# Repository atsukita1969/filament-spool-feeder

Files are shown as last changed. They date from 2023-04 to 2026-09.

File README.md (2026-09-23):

# Filament Spool Feeder for Direct-Drive 3D Printers
# ダイレクト式3Dプリンタ用 フィラメントスプールフィーダー

[日本語](#日本語) | [English](#english)

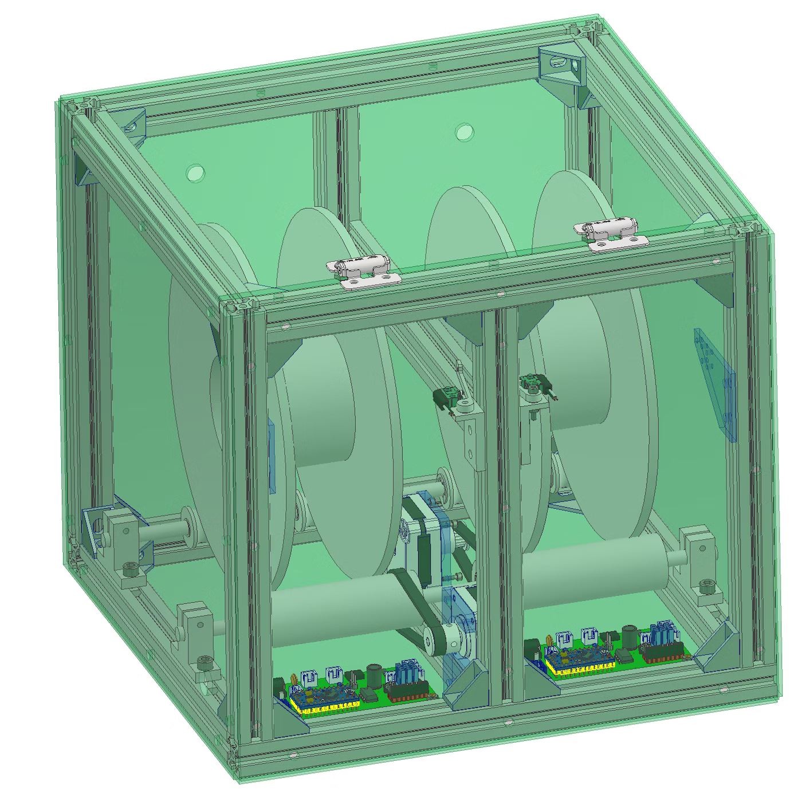
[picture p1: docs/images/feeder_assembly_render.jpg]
Feeder assembly (CAD)


---

## 日本語

### 概要

ダイレクト式（エクストルーダーがヘッドに載っている方式）の3Dプリンタでは、フィラメントをスプールから引き出す力がすべてエクストルーダーにかかります。次のような場面で、フィラメントの引き込みに抵抗がかかり、吐出量が減って品質が落ちます。

- スプールが重い（特に1kg）
- 高速で印刷する
- ノズルがテーブル上でXY方向に大きく移動し、その移動量の分だけフィラメントが引っ張られる

広い部屋ならスプールをプリンタから離して、遊びのフィラメントを長く取れば防げますが、ホビー用途ではその場所がありません。このフィーダーは、ボーデン式とダイレクト式を組み合わせる考え方で、スプールを能動的に回してフィラメントを先に送り出しておく装置です。

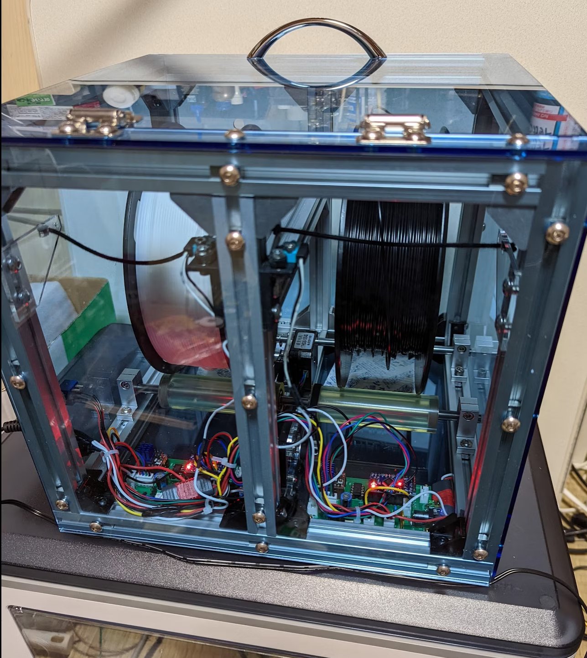
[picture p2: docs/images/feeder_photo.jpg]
Feeder (photo)


### しくみ

1. スプールをウレタンローラーに載せ、ステッピングモーターでGT2ベルトを介してローラーを回します。
2. フィラメントはゴム紐につながったレバーを通ります。一定以上引っ張られるとスイッチが入り、モーターが回ってスプールから送り出します。
3. スイッチが切れた後も一定量（4000ステップ）送り出してから止まります。フィラメントは使用量より多めに送り出され、ゴム紐の伸びとフィラメントのたるみで200mm以上の余裕ができます。
4. 送り要求が異常に長く続いた場合（ジャム）は、独立したマイコン（ATtiny85）がリレーでモーター電源を切り、停止状態を保持します。

詳しくは [docs/principle.md](docs/principle.md) を参照してください。

### リポジトリの構成

| フォルダ | 内容 |
|:--|:--|
| [firmware/](firmware/) | Arduino Pro Mini（メイン制御）と ATtiny85（ジャム監視）のファームウェア |
| [hardware/pcb/](hardware/pcb/) | 制御基板 rev.B（EAGLE データ、回路図 PDF、BOM） |
| [hardware/mechanical/](hardware/mechanical/) | 機構部品（組立外形図、自作部品の STEP データ、BOM） |
| [docs/](docs/) | 原理、配線、画像 |
| [tools/sim/](tools/sim/) | ファームの検証に使った AVR シミュレーション環境 |

### はじめに

1. 機構: [hardware/mechanical/](hardware/mechanical/) の組立外形図、BOM、自作部品の STEP データで組み立てます。
2. 基板: [hardware/pcb/](hardware/pcb/) の EAGLE データで製作します。配線は [docs/wiring.md](docs/wiring.md) にあります。
3. ファーム: [firmware/](firmware/) の手順で、Pro Mini と ATtiny85 に書き込みます。rev.B 基板では、ATtiny85 のファームの `EXT_SENSE_ENABLED` を 1 にします。

### 状態表示LED（改版基板 rev.B）

| LED | 意味 |
|:--|:--|
| 点灯 | 送り要求中 |
| ゆっくり点滅（約1秒周期） | モータードライバが使えない（ジャム監視がモーター電源を切った、など） |
| 速い点滅（約0.25秒周期） | 異常で停止・保持中（リセットで復帰） |
| 消灯 | 待機中 |

### ライセンス

| 対象 | ライセンス |
|:--|:--|
| ハードウェア設計（hardware/） | [CERN-OHL-S-2.0](LICENSES/CERN-OHL-S-2.0.txt) |
| ファームウェアとツール（firmware/, tools/） | [GPL-3.0-or-later](LICENSES/GPL-3.0.txt) |
| 文書と画像（docs/, README など） | [CC BY-SA 4.0](LICENSES/CC-BY-SA-4.0.txt) |

他者のライブラリ、EAGLE ライブラリ要素、購入部品の 3D モデルは対象外です。詳細は [LICENSE.md](LICENSE.md) を参照してください。変更履歴は [CHANGELOG.md](CHANGELOG.md) にあります。2023年に公開した元の状態は、タグ `v1.0-2023` で参照できます。

---

## English

### Overview

On a direct-drive 3D printer (extruder mounted on the print head), the extruder alone has to pull the filament off the spool. The pull resistance reduces the extruded amount and degrades print quality when:

- the spool is heavy (especially 1 kg spools),
- printing fast,
- the nozzle makes long XY travel moves, which pull the filament by the travel distance.

In a large room you can place the spool far from the printer to get a long slack loop, but hobby spaces rarely allow that. This feeder combines the ideas of Bowden and direct drive: it actively turns the spool and pays out filament in advance.

### How it works

1. The spool rests on a urethane roller, driven by a stepper motor through a GT2 belt.
2. The filament passes a lever held by an elastic cord. When the filament is pulled beyond a threshold, a switch closes and the motor turns the spool to pay out filament.
3. After the switch opens, the motor keeps feeding a fixed amount (4000 steps) and stops. More filament is paid out than consumed; the elastic cord and the slack provide more than 200 mm of buffer.
4. If the feed request lasts abnormally long (jam), an independent microcontroller (ATtiny85) cuts the motor supply with a relay and latches the stop.

See [docs/principle.md](docs/principle.md) for details.

### Repository layout

| Folder | Contents |
|:--|:--|
| [firmware/](firmware/) | Firmware for the Arduino Pro Mini (main control) and the ATtiny85 (jam monitor) |
| [hardware/pcb/](hardware/pcb/) | Control board rev.B (EAGLE files, schematic PDF, BOM) |
| [hardware/mechanical/](hardware/mechanical/) | Mechanical parts (outline drawing, STEP files of the self-made parts, BOM) |
| [docs/](docs/) | Principle, wiring, images |
| [tools/sim/](tools/sim/) | AVR simulation used to verify the firmware |

### Getting started

1. Mechanics: build from the outline drawing, the BOM and the STEP files of the self-made parts in [hardware/mechanical/](hardware/mechanical/).
2. Board: make it from the EAGLE files in [hardware/pcb/](hardware/pcb/). Wiring is in [docs/wiring.md](docs/wiring.md).
3. Firmware: flash the Pro Mini and the ATtiny85 as described in [firmware/](firmware/). For board rev.B, set `EXT_SENSE_ENABLED` to 1 in the ATtiny85 firmware.

### Status LED (board rev.B)

| LED | Meaning |
|:--|:--|
| On | Feed requested |
| Slow blink (about 1 s period) | Motor driver not available (e.g. motor supply cut by the jam monitor) |
| Fast blink (about 0.25 s period) | Stopped by a fault and latched (reset to recover) |
| Off | Idle |

### License

| Scope | License |
|:--|:--|
| Hardware design (hardware/) | [CERN-OHL-S-2.0](LICENSES/CERN-OHL-S-2.0.txt) |
| Firmware and tools (firmware/, tools/) | [GPL-3.0-or-later](LICENSES/GPL-3.0.txt) |
| Documentation and images (docs/, README, etc.) | [CC BY-SA 4.0](LICENSES/CC-BY-SA-4.0.txt) |

Third-party libraries, EAGLE library elements and 3D models of purchased parts are not covered. See [LICENSE.md](LICENSE.md). The change history is in [CHANGELOG.md](CHANGELOG.md). The original 2023 state is available as tag `v1.0-2023`.

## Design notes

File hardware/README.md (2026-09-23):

# Hardware / ハードウェア

| Folder / フォルダ | Contents / 内容 |
|:--|:--|
| [pcb/](pcb/) | Control board rev.B: EAGLE files, schematic PDF, BOM / 制御基板 rev.B：EAGLE データ、回路図 PDF、部品表 |
| [mechanical/](mechanical/) | Mechanical parts: outline drawing, STEP files, BOM / 機構部品：組立外形図、STEP データ、部品表 |

Licensed under CERN-OHL-S-2.0, except third-party EAGLE library elements and 3D models of purchased parts. See [LICENSE.md](../LICENSE.md).
CERN-OHL-S-2.0 で公開しています（他者の EAGLE ライブラリ要素と購入部品の 3D モデルを除く）。[LICENSE.md](../LICENSE.md) を参照してください。

Source location: https://github.com/atsukita1969/filament-spool-feeder

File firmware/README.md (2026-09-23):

# Firmware / ファームウェア

[日本語](#日本語) | [English](#english)

| Sketch | MCU | Role |
|:--|:--|:--|
| [feeder_main](feeder_main/) | Arduino Pro Mini (ATmega328P, 5 V, 16 MHz) | Feed control, TMC2130 driver, status LED |
| [jam_monitor_tiny85](jam_monitor_tiny85/) | ATtiny85 | Independent jam monitor, cuts the motor supply with the relay |

Both sketches are compiled by the CI ([.github/workflows/firmware.yml](../.github/workflows/firmware.yml)).

---

## 日本語

### 必要なもの

| 項目 | 内容 |
|:--|:--|
| Arduino IDE | 2.x（または arduino-cli） |
| ボード（メイン） | Arduino AVR Boards の「Arduino Pro or Pro Mini」、Processor「ATmega328P (5V, 16 MHz)」 |
| ボード（ATtiny85） | [ATTinyCore](https://github.com/SpenceKonde/ATTinyCore) 1.5.2 の「ATtiny25/45/85 (No bootloader)」。ボードマネージャ URL: `https://drazzy.com/package_drazzy.com_index.json` |
| ライブラリ | TMCStepper 0.7.3、AccelStepper 1.64（ライブラリマネージャから導入） |
| 書き込み器 | Pro Mini: USB シリアル変換（FTDI 6ピン）。ATtiny85: ISP 書き込み器（Arduino as ISP、USBasp など） |

旧版で使っていた TMC2130Stepper ライブラリは作者により非推奨となったため、後継の TMCStepper に移行しました。TMC2130 に書き込む設定値は旧版と同一です。

### Pro Mini への書き込み（feeder_main）

1. `feeder_main/feeder_main.ino` を開きます（`config.h` も同じフォルダに必要です）。
2. ボード「Arduino Pro or Pro Mini」、Processor「ATmega328P (5V, 16 MHz)」を選びます。
3. USB シリアル変換を Pro Mini の FTDI ヘッダにつなぎ、書き込みます。

### ATtiny85 への書き込み（jam_monitor_tiny85）

ATtiny85 は DIP ソケットに載っているので、基板から外して ISP 書き込み器で書き込みます。

1. ボード「ATtiny25/45/85 (No bootloader)」、Chip「ATtiny85」、Clock「8 MHz (internal)」、B.O.D.「B.O.D. Enabled (2.7v)」を選びます。
2. 書き込み器を選び、「ブートローダを書き込む」を実行します。ブートローダは書き込まれず、クロックと B.O.D. のヒューズだけが設定されます。新品の ATtiny85 は 1 MHz 設定なので、この操作をしないと時間が 8 倍に延びます。
3. 「書き込み装置を使って書き込む」でスケッチを書き込みます。
4. rev.B 基板（X5 を PB4 に接続した基板）では、`EXT_SENSE_ENABLED` を 1 にしてから書き込みます。

### 設定（feeder_main/config.h）

| 項目 | 既定値 | 内容 |
|:--|:--|:--|
| `FEED_STEPS` | 4000 | スイッチ OFF 後の送りステップ数 |
| `MOTION_MODE` | `MOTION_EXPLICIT` | 送りの動かし方。`MOTION_LEGACY` で 2023 年版と同じ呼び出し方になります |
| `EXPLICIT_MAX_SPEED` | 2400 | スイッチ ON 中の最高速度（ステップ/s） |
| `EXPLICIT_ACCEL_UP` | 4000 | ON 中の加速度（ステップ/s²） |
| `EXPLICIT_DECEL` | 2000 | OFF 後の減速度（ステップ/s²） |
| `RUN_CURRENT_MA` / `HOLD_MULT` | 600 / 0.5 | モーター電流（RMS）と保持電流の比 |
| `INPUT_FILTER_MS` | 5 | 送り要求入力のフィルタ時間 |
| `DRIVER_CHECK_MS` | 500 | TMC2130 の状態確認の周期 |
| `BACKUP_TIMEOUT_MS` | 53000 | ソフトウェア側のジャム判定（0 で無効） |

各値の根拠は [docs/principle.md](../docs/principle.md) にあります。

### 設定（jam_monitor_tiny85.ino の先頭）

| 項目 | 既定値 | 内容 |
|:--|:--|:--|
| `JAM_TIMEOUT_MS` | 48000 | 送り要求がこの時間続いたらモーター電源を切る |
| `RELEASE_FILTER_MS` | 20 | これより短い OFF では計時をリセットしない |
| `EXT_SENSE_ENABLED` | 0 | 1 = rev.B 基板の外部入力（PB4）を使う |
| `EXT_FAULT_FILTER_MS` | 50 | 外部入力がこの時間 LOW で異常と判定 |
| `EXT_STARTUP_GRACE_MS` | 1000 | 電源投入後、外部入力が正常になるまで待つ時間 |

### シリアル出力（Pro Mini、115200 bps）

| メッセージ | 意味 |
|:--|:--|
| `feeder_main start` | 起動 |
| `TMC2130: configured and verified` | ドライバ設定完了 |
| `TMC2130: reset / undervoltage detected (motor supply interrupted?)` | モーター電源の瞬断などでドライバがリセットされた（自動で再設定） |
| `TMC2130: not responding` | ドライバが応答しない（モーター電源が切れている、など） |
| `FAULT: TMC2130 overtemperature or short circuit. Latched until reset.` | 過熱・短絡で停止 |
| `FAULT: feed request active too long (jam?). Latched until reset.` | ソフトウェア側のジャム判定で停止 |

### 検証

旧版と新版のバイナリを AVR シミュレーターで動かし、送りの動き、TMC2130 のレジスタ値、保護機能を比較しました。手順と結果は [tools/sim](../tools/sim/) にあります。

---

## English

### Requirements

| Item | Details |
|:--|:--|
| Arduino IDE | 2.x (or arduino-cli) |
| Board (main) | Arduino AVR Boards, "Arduino Pro or Pro Mini", Processor "ATmega328P (5V, 16 MHz)" |
| Board (ATtiny85) | [ATTinyCore](https://github.com/SpenceKonde/ATTinyCore) 1.5.2, "ATtiny25/45/85 (No bootloader)". Boards Manager URL: `https://drazzy.com/package_drazzy.com_index.json` |
| Libraries | TMCStepper 0.7.3, AccelStepper 1.64 (Library Manager) |
| Programmer | Pro Mini: USB-serial adapter (6-pin FTDI). ATtiny85: ISP programmer (Arduino as ISP, USBasp, ...) |

The TMC2130Stepper library used by the old version has been deprecated by its author, so the firmware now uses its successor TMCStepper. The values written to the TMC2130 are identical to the old version.

### Flashing the Pro Mini (feeder_main)

1. Open `feeder_main/feeder_main.ino` (`config.h` must be in the same folder).
2. Select "Arduino Pro or Pro Mini", Processor "ATmega328P (5V, 16 MHz)".
3. Connect a USB-serial adapter to the FTDI header of the Pro Mini and upload.

### Flashing the ATtiny85 (jam_monitor_tiny85)

The ATtiny85 sits in a DIP socket. Take it out and program it with an ISP programmer.

1. Select "ATtiny25/45/85 (No bootloader)", Chip "ATtiny85", Clock "8 MHz (internal)", B.O.D. "B.O.D. Enabled (2.7v)".
2. Select the programmer and run "Burn Bootloader". No bootloader is written; this only sets the clock and B.O.D. fuses. A new ATtiny85 runs at 1 MHz, so without this step all times become 8 times longer.
3. Upload with "Upload Using Programmer".
4. For board rev.B (X5 wired to PB4), set `EXT_SENSE_ENABLED` to 1 before uploading.

### Settings (feeder_main/config.h)

| Item | Default | Meaning |
|:--|:--|:--|
| `FEED_STEPS` | 4000 | Steps fed after the switch opens |
| `MOTION_MODE` | `MOTION_EXPLICIT` | Motion profile. `MOTION_LEGACY` uses the same call pattern as the 2023 firmware |
| `EXPLICIT_MAX_SPEED` | 2400 | Top speed while the switch is on (steps/s) |
| `EXPLICIT_ACCEL_UP` | 4000 | Acceleration while the switch is on (steps/s²) |
| `EXPLICIT_DECEL` | 2000 | Deceleration after the switch opens (steps/s²) |
| `RUN_CURRENT_MA` / `HOLD_MULT` | 600 / 0.5 | Motor current (RMS) and hold current ratio |
| `INPUT_FILTER_MS` | 5 | Filter time of the feed request input |
| `DRIVER_CHECK_MS` | 500 | TMC2130 check period |
| `BACKUP_TIMEOUT_MS` | 53000 | Software jam timeout (0 = off) |

The reasoning behind the values is in [docs/principle.md](../docs/principle.md).

### Settings (top of jam_monitor_tiny85.ino)

| Item | Default | Meaning |
|:--|:--|:--|
| `JAM_TIMEOUT_MS` | 48000 | Cut the motor supply when the feed request lasts this long |
| `RELEASE_FILTER_MS` | 20 | Shorter off periods do not reset the timer |
| `EXT_SENSE_ENABLED` | 0 | 1 = use the external input (PB4) of board rev.B |
| `EXT_FAULT_FILTER_MS` | 50 | External input LOW this long = fault |
| `EXT_STARTUP_GRACE_MS` | 1000 | Time after power-up for the external input to become OK |

### Serial output (Pro Mini, 115200 bps)

| Message | Meaning |
|:--|:--|
| `feeder_main start` | Start-up |
| `TMC2130: configured and verified` | Driver configured |
| `TMC2130: reset / undervoltage detected (motor supply interrupted?)` | Driver was reset, e.g. by a short motor supply interruption (reconfigured automatically) |
| `TMC2130: not responding` | Driver does not respond (e.g. motor supply cut) |
| `FAULT: TMC2130 overtemperature or short circuit. Latched until reset.` | Stopped on overtemperature or short circuit |
| `FAULT: feed request active too long (jam?). Latched until reset.` | Stopped by the software jam timeout |

### Verification

The old and new binaries were run in an AVR simulator to compare motion, TMC2130 register values and protection functions. See [tools/sim](../tools/sim/).

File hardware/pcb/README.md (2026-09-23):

# Control board / 制御基板

[日本語](#日本語) | [English](#english)

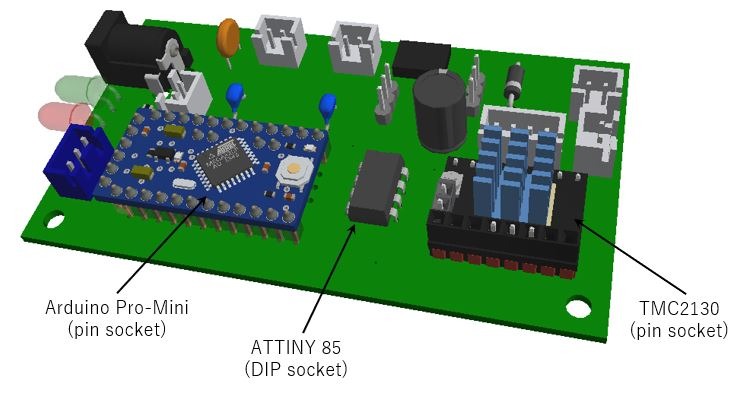
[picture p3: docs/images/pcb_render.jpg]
PCB render (rev.A)


---

## 日本語

### ファイル

| ファイル | 内容 |
|:--|:--|
| [eagle/spool_tmc2130_b.sch](eagle/spool_tmc2130_b.sch) | 回路図 rev.B（Autodesk Fusion から EAGLE 9.7.0 形式で書き出し、XML） |
| [eagle/spool_tmc2130_b.brd](eagle/spool_tmc2130_b.brd) | 基板 rev.B（同上、2層、50 × 90 mm） |
| [spool_tmc2130_b_schematic.pdf](spool_tmc2130_b_schematic.pdf) | 回路図 rev.B の PDF（A3） |
| [bom.csv](bom.csv) | 部品表（rev.A の実装品と rev.B） |

EAGLE データは Autodesk Fusion の Electronics で開けます。KiCad でも取り込めます。配線とピン割り当ては [docs/wiring.md](../../docs/wiring.md) にあります。上の画像は rev.A の基板です。

rev.A（製作済み。発注に使ったデータ）は、タグ [`pcb-rev.A`](https://github.com/atsukita1969/filament-spool-feeder/tree/pcb-rev.A/hardware/pcb) から取り出せます。

### rev.A と rev.B に共通の注意点

- GND は配線ではなく表裏のベタだけで接続しています。
- リレー K1 のコイルは 5V 駆動です。部品は G6K-2P-Y **DC5** を使ってください（DC12 品は 5V では動作しません）。

### rev.B の変更点

| # | 変更 | 理由 |
|:--|:--|:--|
| 1 | X5 の2番と JP2 の1番を EXT_IN から外し、新しいネット EXT_SENSE として ATtiny85 PB4（3番ピン）へ接続。R5（10kΩ）でプルダウン | 外部センサーの異常でモーター電源を切れるようにするため（rev.A では ATtiny85 の出力と衝突して機能しない）。HIGH = 正常、LOW または断線 = 異常。JP2 の1-2 短絡で「外部センサーなし」 |
| 2 | EXT_SENSE と PB4 の間に R6（10kΩ）を直列に追加 | X5 に 5V を超える電圧（最大 12V）が加わっても、ATtiny85 の入力保護ダイオードに流れる電流を約 0.65mA に抑えるため |
| 3 | T1 を DTC144EKA から DTC123JKA に変更（同じ SMT3、同じ端子配置） | 入力電流が 68〜126µA から 1.45〜2.69mA に増え、コイル電流 21.1mA で確実に飽和する |
| 4 | R2 を 680Ω から 2.2kΩ に変更 | 抵抗の損失を約 0.045W に下げる |
| 5 | D3 を D4 ネットから外し、Pro Mini D8 → D3 → R4 → GND で駆動。R4 を 150Ω から 470Ω に変更 | X9 にどの種類のセンサーでも接続できるようにし、LED で状態を表示するため。D8 の電流は約 6mA |
| 6 | チップ抵抗 R1〜R6 を 0603 から 0805（2012）に変更 | 手はんだをしやすくするため |

部品の配置：R5 は X5 の近く、R6 は U2 の近くにあります。R2 と R3 は表面、ほかのチップ部品（R1、R4、R5、R6、T1、U1）は裏面です。

### rev.B の使い方

- ATtiny85 のファームは `EXT_SENSE_ENABLED` を 1 にして書き込みます（[firmware/](../../firmware/)）。
- 外部センサーを使わないときは、JP2 の1-2 を短絡します。
- X5 には、正常なときに2番を HIGH にするセンサーをつなぎます。例：1-2 間の常閉接点（正常で閉じ、異常や断線で開く）、または 5〜12V を出力するセンサー。NPN オープンコレクタ出力は HIGH を出せないので、そのままでは使えません。

### rev.B の確認

- DRC は、GND の小さい SMD パッド5か所（T1 のE、R1・R3・R4・R5 の1番）で「銅箔幅」を報告します。パッドの短辺（1.0〜1.03mm）が GND ネットクラスの最小幅 1.524mm より細いためで、パッドはベタに直接つながっています。ほかのエラーはありません。
- 製造データ（CAM 出力のガーバー）の銅箔を解析し、26 ネットすべてが設計どおりにつながり、ショートや孤立した銅箔がないことを確かめました。

### rev.A（製作済み）の注意点

- T1（DTC144EKA）はデータシート上の駆動能力に余裕がありません。実機では動いていますが、rev.B で変更しました。
- R2（680Ω、0603）は 12V で約 0.15W 消費し、一般的な 0603 抵抗の定格 0.1W を超えます。
- ATtiny85 を実装したまま JP2 を短絡しないでください。
- 以前公開していた DesignSpark 版のデータは、EAGLE からの変換時に GND ベタが GND ネットから外れていたため削除しました。タグ `v1.0-2023` から参照できます。

ファームは rev.A と rev.B の両方に対応しています（[firmware/](../../firmware/)）。

---

## English

### Files

| File | Contents |
|:--|:--|
| [eagle/spool_tmc2130_b.sch](eagle/spool_tmc2130_b.sch) | Schematic rev.B (exported from Autodesk Fusion in EAGLE 9.7.0 format, XML) |
| [eagle/spool_tmc2130_b.brd](eagle/spool_tmc2130_b.brd) | Board rev.B (same format, 2 layers, 50 × 90 mm) |
| [spool_tmc2130_b_schematic.pdf](spool_tmc2130_b_schematic.pdf) | Schematic rev.B as PDF (A3) |
| [bom.csv](bom.csv) | Bill of materials (rev.A as built and rev.B) |

The EAGLE files open in Autodesk Fusion Electronics and can be imported into KiCad. Wiring and pin assignment are in [docs/wiring.md](../../docs/wiring.md). The picture above shows the rev.A board.

rev.A (built; the data used for fabrication) is available in tag [`pcb-rev.A`](https://github.com/atsukita1969/filament-spool-feeder/tree/pcb-rev.A/hardware/pcb).

### Notes for both rev.A and rev.B

- GND is connected only through the top and bottom copper pours, not by traces.
- The coil of relay K1 is driven from 5 V. Use G6K-2P-Y **DC5** (the DC12 version does not operate on 5 V).

### Changes in rev.B

| # | Change | Reason |
|:--|:--|:--|
| 1 | Disconnect X5 pin 2 and JP2 pin 1 from EXT_IN and route them as a new net EXT_SENSE to ATtiny85 PB4 (pin 3), with a 10 kΩ pull-down R5 | Lets an external sensor cut the motor supply (on rev.A it conflicts with the ATtiny85 output and does not work). HIGH = OK, LOW or broken wire = fault. JP2 1-2 fitted = no external sensor |
| 2 | Add R6 (10 kΩ) in series between EXT_SENSE and PB4 | Limits the current into the input protection diode of the ATtiny85 to about 0.65 mA when more than 5 V (up to 12 V) is applied to X5 |
| 3 | T1: DTC144EKA → DTC123JKA (same SMT3 package and pinout) | Input current rises from 68–126 µA to 1.45–2.69 mA, so the transistor saturates reliably at the 21.1 mA coil current |
| 4 | R2: 680 Ω → 2.2 kΩ | Reduces the resistor dissipation to about 0.045 W |
| 5 | Disconnect D3 from the D4 net and drive it from Pro Mini D8 → D3 → R4 → GND; R4: 150 Ω → 470 Ω | Any type of sensor can then be used on X9, and the LED shows the status. D8 current about 6 mA |
| 6 | Chip resistors R1–R6: 0603 → 0805 (2012) | Easier hand soldering |

Placement: R5 is near X5 and R6 is near U2. R2 and R3 are on the top side; the other chip parts (R1, R4, R5, R6, T1, U1) are on the bottom side.

### Using rev.B

- Flash the ATtiny85 with `EXT_SENSE_ENABLED` set to 1 ([firmware/](../../firmware/)).
- Fit JP2 1-2 when no external sensor is used.
- Connect a sensor to X5 that drives pin 2 HIGH when everything is OK, for example a normally closed contact between pins 1 and 2 (closed = OK, open or broken wire = fault), or a sensor with a 5–12 V output. An NPN open-collector output cannot drive HIGH and does not work as is.

### Checks on rev.B

- The DRC reports "copper width" at five small GND SMD pads (T1 E, pin 1 of R1, R3, R4 and R5). The short side of these pads (1.0–1.03 mm) is narrower than the 1.524 mm minimum width of the GND net class; the pads are connected directly to the pour. There are no other errors.
- The copper of the manufacturing data (Gerber files from the CAM processor) was analysed: all 26 nets are connected as designed, with no shorts and no isolated copper.

### Notes on rev.A (built)

- T1 (DTC144EKA) has no guaranteed drive margin according to its datasheet. It works on the built boards but was changed in rev.B.
- R2 (680 Ω, 0603) dissipates about 0.15 W at 12 V, above the 0.1 W rating of a standard 0603 resistor.
- Do not fit JP2 while the ATtiny85 is installed.
- The DesignSpark files published earlier were removed because the GND pour lost its connection to the GND net in the conversion from EAGLE. They are still available in tag `v1.0-2023`.

The firmware supports both rev.A and rev.B ([firmware/](../../firmware/)).

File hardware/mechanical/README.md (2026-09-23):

# Mechanical parts / 機構部品

[日本語](#日本語) | [English](#english)

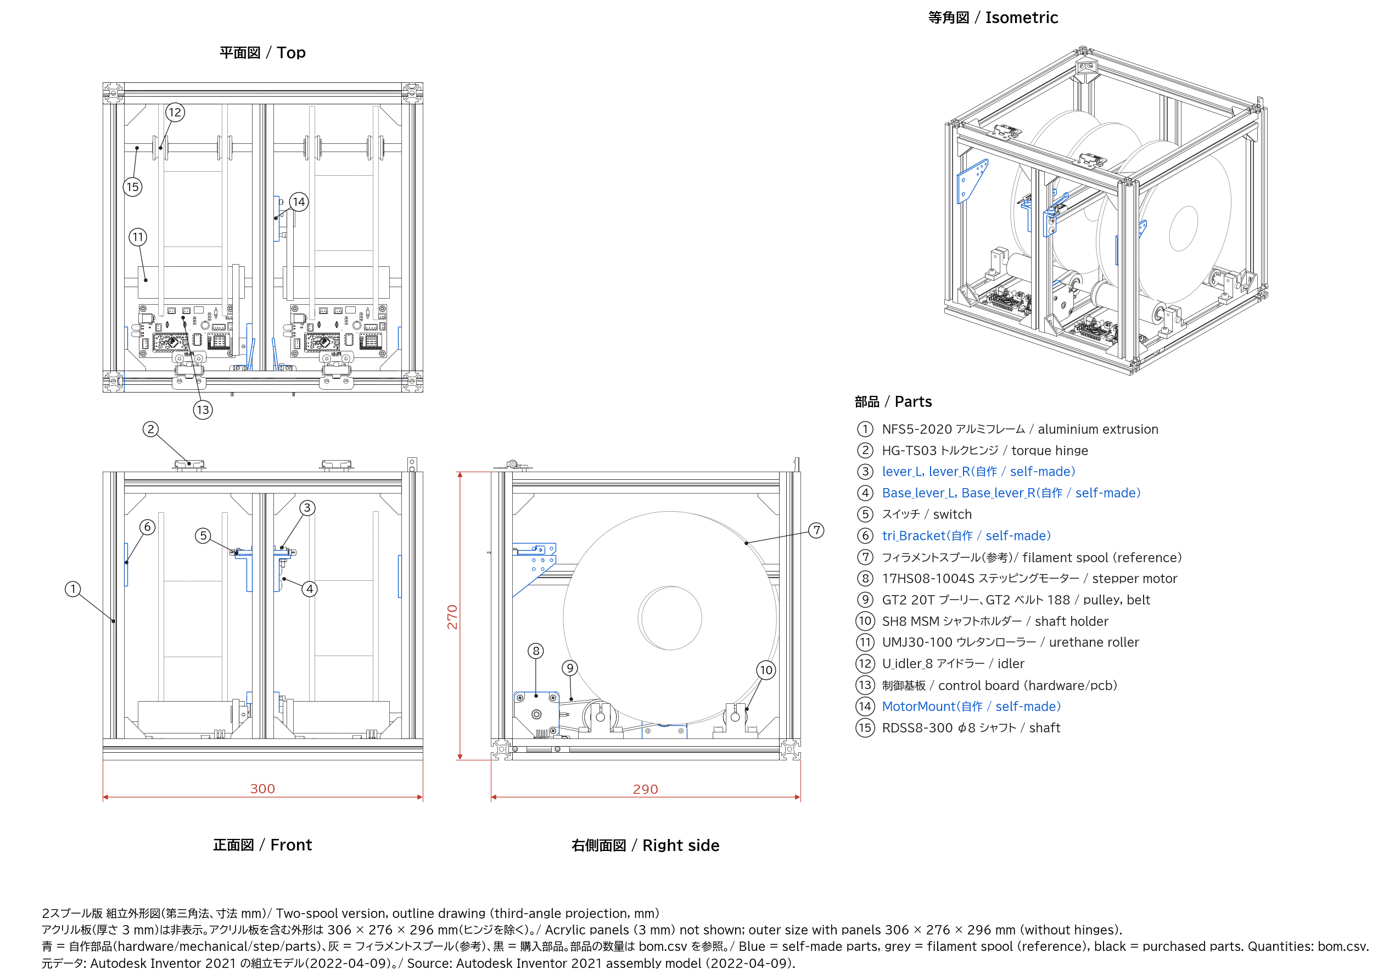
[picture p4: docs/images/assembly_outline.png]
Outline drawing


---

## 日本語

| ファイル | 内容 |
|:--|:--|
| [../../docs/images/assembly_outline.png](../../docs/images/assembly_outline.png) | 2スプール版の組立外形図（正面図、平面図、右側面図、等角図、部品番号） |
| [../../docs/images/feeder_assembly_render.jpg](../../docs/images/feeder_assembly_render.jpg) | 2スプール版のレンダリング画像 |
| [step/parts/](step/parts/) | 自作部品の STEP（Base_lever_L/R、lever_L/R、MotorMount、tri_Bracket、アクリル板6種） |
| [bom.csv](bom.csv) | 部品表 |
| [assembly_parts.csv](assembly_parts.csv) | 組立モデル（Autodesk Inventor、2022-04-09）に含まれていた部品と数量 |

全体組立の STEP（assy_top_dual.stp）は、購入部品のメーカー提供 3D モデルを含んでいたため、2026年に削除しました。代わりに組立外形図と部品表を置いています。購入部品の 3D モデルは、部品表の型番で各メーカーから入手してください。

樹脂の自作部品（Base_lever、lever、MotorMount、tri_Bracket）は精度を必要としないので、3D プリンタでの製作を想定しています。アクリル板（厚さ 3 mm の6種、20x300x3 と *_plate_wall）は、STEP の外形と穴位置に合わせて切断と穴あけをします。アクリル板の STEP は、組立モデルから形状を変えずに取り出したものです。

駆動系: モーター（17HS08-1004S）の GT2 20歯プーリーから、GT2 無端ベルト 188mm をウレタンローラー（外径30mm）に直接巻き掛けています。ローラー側にプーリーはありません。詳しくは [docs/principle.md](../../docs/principle.md) を参照してください。

---

## English

| File | Contents |
|:--|:--|
| [../../docs/images/assembly_outline.png](../../docs/images/assembly_outline.png) | Outline drawing of the two-spool version (front, top, right side, isometric, part numbers) |
| [../../docs/images/feeder_assembly_render.jpg](../../docs/images/feeder_assembly_render.jpg) | Rendering of the two-spool version |
| [step/parts/](step/parts/) | STEP files of the self-made parts (Base_lever_L/R, lever_L/R, MotorMount, tri_Bracket, six acrylic plates) |
| [bom.csv](bom.csv) | Bill of materials |
| [assembly_parts.csv](assembly_parts.csv) | Parts and quantities in the assembly model (Autodesk Inventor, 2022-04-09) |

The complete assembly STEP (assy_top_dual.stp) was removed in 2026 because it contained manufacturer 3D models of purchased parts. The outline drawing and the bills of materials replace it. Get the 3D models of purchased parts from their manufacturers by the part numbers in the BOM.

The self-made plastic parts (Base_lever, lever, MotorMount, tri_Bracket) need no high precision and are meant to be 3D printed. The six acrylic plates (3 mm, 20x300x3 and *_plate_wall) are cut and drilled to the outline and holes of their STEP files. The plate STEP files were extracted unchanged from the assembly model.

Drive: a GT2 20T pulley on the motor (17HS08-1004S) drives a GT2 closed-loop belt of 188 mm that runs directly on the urethane roller (outer diameter 30 mm). There is no pulley on the roller. See [docs/principle.md](../../docs/principle.md).

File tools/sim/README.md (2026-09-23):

# Firmware simulation / ファームのシミュレーション検証

[日本語](#日本語) | [English](#english)

---

## 日本語

コンパイル済みのファーム（.elf）を [simavr](https://github.com/buserror/simavr) で命令単位に実行し、旧版（2023年）と新版を比較するための環境です。

| ファイル | 内容 |
|:--|:--|
| `sim328.c` | Pro Mini（ATmega328P 16MHz）と TMC2130 の SPI 動作モデル。STEP パルス、EN、LED、TMC2130 レジスタの書き込みを記録 |
| `simtiny.c` | ATtiny85（8MHz）。PB1（送り要求）と PB4（外部入力）を操作し、PB3（リレー駆動）を監視 |
| `analyze.py` | 速度プロファイルの解析（立ち上がり加速度、最高速度、解除後の送り） |
| `ledsum.py` | LED の点灯・点滅パターンの要約 |
| `scenarios/` | 試験シナリオ（1行 = `時刻ms イベント 値`、最後の行は `時刻ms END 0`） |

TMC2130 モデルは、VM（モーター電源）が切れている間は SPI に応答せず、VM が入ると全レジスタが 0 になって GSTAT.reset が立ちます（モジュールのロジック部が VM から給電される、最も厳しい場合を想定）。simavr 1.6 は SPI の1バイトを 100µs として扱うため、SPI 通信中の時間は実機より長く出ます。

### 使い方（Ubuntu）

```
sudo apt install simavr libsimavr-dev libelf-dev
gcc -O2 -o sim328 sim328.c -I/usr/include/simavr -lsimavr -lelf -lm
gcc -O2 -o simtiny simtiny.c -I/usr/include/simavr -lsimavr -lelf -lm
arduino-cli compile -b arduino:avr:pro:cpu=16MHzatmega328 --output-dir out ../../firmware/feeder_main
./sim328 out/feeder_main.ino.elf scenarios/scA.txt log.txt
python3 analyze.py out/feeder_main.ino.elf scenarios/scA.txt 1.0 4.0
```

イベント: `sim328` は `D4`（送り要求）、`VM`（モーター電源）、`ERR`（TMC2130 の過熱・短絡）。`simtiny` は `REQ`（送り要求）、`EXT`（外部入力）。

### 結果（2026年9月）

| シナリオ | 内容 | 旧版 | 新版 |
|:--|:--|:--|:--|
| scA | 1〜4秒 送り要求 | ON中 2,386 ステップ/s、解除直後 3,900 へ跳ね上がり、解除後 4,000 ステップ | ON中 約2,356、跳ね上がりなし、解除後 約4,000 ステップ。TMC2130 レジスタ値は同一 |
| scShort | 0.3秒 送り要求 | 解除後 2,900 ステップ/s まで加速、合計 4,200 ステップ | 2,400 で頭打ち、合計 4,209 ステップ |
| scRepress | 解除 0.6秒後に再要求 | 3,900 へ跳ね上がった後 2,340 へ急減速 | 一定速度 |
| scLateVM | VM を 0.5秒遅れて投入 | 回らない（設定が消える） | 0.51秒で設定完了 |
| scGlitch | 送り中に VM を 50ms 遮断 | 以後回らない | 2.51秒に再設定して復帰 |
| scVMcut | 送り中に VM を遮断したまま | ― | LED 遅い点滅 |
| scErr | 送り中に TMC2130 異常 | ― | 2.00秒に停止保持、LED 速い点滅 |
| scJam60 | 送り要求を 59秒保持 | 回り続ける | 要求から 53秒で停止保持 |
| t1 | ATtiny85: 連続要求 | 47.9秒でリレー OFF | 48.0秒でリレー OFF |
| t2 | ATtiny85: 短い要求 200回 | 31.5% の解除でカウンタが戻らない（停止はせず） | 誤停止なし |
| t3 | ATtiny85: 25秒の要求 12回 | 2回目で誤停止 | 誤停止なし |
| t4 | ATtiny85: 1秒ごとに 5ms のばたつき | ― | 48秒で停止 |
| t5 | ATtiny85: 30ms の OFF の後も要求継続 | ― | OFF でリセットされ、その 48秒後に停止 |
| e1〜e4, e2b | ATtiny85 rev.B: 外部入力 | ― | 30ms の LOW では止まらず 80ms で停止、起動時に正常にならなければリレーを入れずに保持、ジャム判定は同じ |

ウォッチドッグは、`loop()` を意図的に止めた試験用ビルドで、約1秒後にリセットされ停止を保持することを確認しました。

---

## English

An environment that runs the compiled firmware (.elf) instruction by instruction in [simavr](https://github.com/buserror/simavr) to compare the old (2023) and new versions.

| File | Contents |
|:--|:--|
| `sim328.c` | Pro Mini (ATmega328P 16 MHz) with an SPI model of the TMC2130. Records STEP pulses, EN, LED and TMC2130 register writes |
| `simtiny.c` | ATtiny85 (8 MHz). Drives PB1 (feed request) and PB4 (external input), watches PB3 (relay drive) |
| `analyze.py` | Speed profile analysis (ramp-up acceleration, top speed, feed after release) |
| `ledsum.py` | Summary of the LED on/blink pattern |
| `scenarios/` | Test scenarios (one line = `time_ms EVENT value`, last line `time_ms END 0`) |

The TMC2130 model does not answer on SPI while VM (motor supply) is off; when VM comes on, all registers are 0 and GSTAT.reset is set (worst case: the module logic is supplied from VM). simavr 1.6 treats one SPI byte as 100 µs, so time spent in SPI transfers is longer than on real hardware.

### Usage (Ubuntu)

```
sudo apt install simavr libsimavr-dev libelf-dev
gcc -O2 -o sim328 sim328.c -I/usr/include/simavr -lsimavr -lelf -lm
gcc -O2 -o simtiny simtiny.c -I/usr/include/simavr -lsimavr -lelf -lm
arduino-cli compile -b arduino:avr:pro:cpu=16MHzatmega328 --output-dir out ../../firmware/feeder_main
./sim328 out/feeder_main.ino.elf scenarios/scA.txt log.txt
python3 analyze.py out/feeder_main.ino.elf scenarios/scA.txt 1.0 4.0
```

Events: `sim328` uses `D4` (feed request), `VM` (motor supply), `ERR` (TMC2130 overtemperature/short). `simtiny` uses `REQ` (feed request) and `EXT` (external input).

### Results (September 2026)

| Scenario | Description | Old | New |
|:--|:--|:--|:--|
| scA | Feed request 1–4 s | 2,386 steps/s while requested, jumps to 3,900 at release, 4,000 steps after release | about 2,356, no jump, about 4,000 steps after release. Identical TMC2130 register values |
| scShort | Feed request 0.3 s | Accelerates to 2,900 steps/s after release, 4,200 steps in total | Capped at 2,400, 4,209 steps in total |
| scRepress | New request 0.6 s after release | Jumps to 3,900, then drops abruptly to 2,340 | Constant speed |
| scLateVM | VM switched on 0.5 s late | Does not move (configuration lost) | Configured at 0.51 s |
| scGlitch | VM interrupted for 50 ms while feeding | Never moves again | Reconfigured and recovered at 2.51 s |
| scVMcut | VM cut while feeding and left off | – | LED slow blink |
| scErr | TMC2130 fault while feeding | – | Stop latched at 2.00 s, LED fast blink |
| scJam60 | Feed request held for 59 s | Keeps running | Stop latched 53 s after the request |
| t1 | ATtiny85: continuous request | Relay off at 47.9 s | Relay off at 48.0 s |
| t2 | ATtiny85: 200 short requests | Counter not reset on 31.5% of releases (no stop) | No false stop |
| t3 | ATtiny85: 12 requests of 25 s | False stop on the second request | No false stop |
| t4 | ATtiny85: 5 ms bounce every second | – | Stops at 48 s |
| t5 | ATtiny85: 30 ms off, request continues | – | Reset by the off period, stops 48 s later |
| e1–e4, e2b | ATtiny85 rev.B: external input | – | No stop on 30 ms LOW, stop on 80 ms; relay stays off and latched if the input is not OK at start-up; jam detection unchanged |

The watchdog was checked with a test build that deliberately stops `loop()`: the MCU is reset after about 1 s and the stop is latched.

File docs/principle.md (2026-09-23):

# 原理と制御 / Principle and control

[日本語](#日本語) | [English](#english)

---

## 日本語

### 1. 解決したい問題

ダイレクト式のプリンタでは、エクストルーダーがスプールからフィラメントを引き出します。スプールの慣性と回転抵抗は、そのままエクストルーダーの負荷になります。

最も大きい負荷は、ノズルがテーブル上でXY方向に大きく移動したときの引っ張りです。移動した距離の分だけフィラメントが引っ張られるため、消費量とは関係なく供給側に負荷がかかります。

### 2. 構成

```
ステッピングモーター 17HS08-1004S (1.8°)
  └ GT2 20歯プーリー ─ GT2無端ベルト 188mm ─ ウレタンローラー φ30（プーリーなし、ベルトを直接巻き掛け）
       └ スプールの縁（外周）がローラーに載り、摩擦で回る
            └ フィラメント ─ ゴム紐付きレバー（スイッチ） ─ プリンタ
```

### 3. 送り出しの制御

- ゴム紐付きのレバーが一定以上引っ張られるとスイッチが入り、モーターが回ってスプールから送り出します。
- スイッチが切れた後も 4000 ステップ送ってから止まります。
- フィラメントは使用量より多めに送り出されます。ゴム紐の伸びとフィラメントのたるみで 200mm 以上の余裕があり、XY 移動による引っ張りを吸収します。
- 送り出し量はスプールの残量（巻き径）で変わりますが、この余裕で吸収されます。

### 4. 駆動系の幾何

| 項目 | 値 | 根拠 |
|:--|:--|:--|
| プーリーのピッチ径 | 12.73 mm | 20歯 × 2mm ÷ π |
| ローラー上のベルト心線の径 | 約 32.0 mm | φ30 ＋ 2 ×（歯高 0.75 ＋ ピッチライン 0.254） |
| 角速度の減速比 | 約 2.51 | 32.0 ÷ 12.73（歯がウレタンに食い込む程度により 2.40〜2.51） |
| モーター1回転あたりのローラー表面移動 | 約 37.5 mm | 40 mm × 15 ÷ 16.0 |
| ローラー表面 1 mm あたりのステップ数 | 約 85.4 | 3200 ステップ/回転（1/16）÷ 37.5 mm |

スプールの縁の径は一定なので、スプールの回転速度は一定です。フィラメントの送り速度は「ローラー表面速度 ×（巻き径 ÷ 縁の径）」で、スプールの残量によって変わります（例：縁 φ180、芯 φ80 のスプールでは 0.44〜1.0 倍）。

### 5. 送り制御の値

2023年版ファームの値をそのまま使っています。旧ファームは `move()` を毎ループ呼ぶため、実際の動きは設定値と異なっていました。新ファームは、その実際の動きを明示的な値で再現し、スイッチが切れた瞬間の速度の跳ね上がりだけを取り除いています（AVR シミュレーションで確認。[tools/sim](../tools/sim/)）。

| 項目 | 旧ファームの設定値 | 旧ファームの実際の動き | 新ファーム |
|:--|:--|:--|:--|
| 最高速度（スイッチ ON 中） | 4000 ステップ/s | 約 2,390 ステップ/s | 2400 ステップ/s（実測 約 2,360） |
| 立ち上がりの加速度 | 2000 ステップ/s² | 約 3,800 ステップ/s² | 4000 ステップ/s² |
| スイッチ OFF 直後 | ― | 約 3,900 ステップ/s に跳ね上がり | 跳ね上がりなし |
| OFF 後の減速度 | 2000 ステップ/s² | 約 1,960 ステップ/s² | 2000 ステップ/s² |
| OFF 後の送り | 4000 ステップ | 4000 ステップ | 4000 ステップ |
| マイクロステップ、電流 | 1/16、600 mA RMS、stealthChop | 同左 | 同左（TMC2130 のレジスタ値も同一） |

2400 ステップ/s はローラー表面で約 28 mm/s、4000 ステップはローラー表面で約 47 mm です。

### 6. 保護機能

**ジャム監視（ATtiny85、メインの Pro Mini から独立）**

- 送り要求（スイッチ ON）が 48 秒連続したら、リレーでモーター電源（VM）を切り、停止を保持します。48 秒は 2023 年版の実効値に合わせています。
- 20 ms 未満の OFF（接点のばたつき）では計時をリセットしません。
- ATtiny85 自身が停止した場合は、ウォッチドッグでリセットしたうえで停止を保持します。
- 停止中は出力をハイインピーダンスにし、プルダウン抵抗でリレーを OFF にします。
- リセットスイッチ（X3）は Pro Mini と ATtiny85 の両方をリセットし、停止の保持を解除します。
- 改版基板（rev.B）では外部入力（X5）を ATtiny85 に接続します。外部センサーが異常（LOW または断線）を示したときも、同じようにモーター電源を切ります。

**ドライバ監視（Pro Mini）**

- TMC2130 の設定を書き込んだ後に読み戻して確認し、確認できてからドライバを有効にします。
- 500 ms ごとに TMC2130 の状態を確認します。モーター電源の瞬断などでドライバがリセットされた場合は、自動的に設定し直します。
- 過熱・短絡を検出したら、ドライバを止めて保持します。
- 送り要求が 53 秒続いた場合も、ソフトウェア側でモーターを止めて保持します（ATtiny85 の予備）。

---

## English

### 1. Problem

On a direct-drive printer the extruder pulls the filament off the spool, so the spool inertia and friction load the extruder directly.

The largest load comes from long XY travel moves of the nozzle. The filament is pulled by the travel distance, regardless of how much is being extruded.

### 2. Construction

```
Stepper motor 17HS08-1004S (1.8 deg)
  └ GT2 20T pulley ─ GT2 closed-loop belt 188 mm ─ urethane roller dia. 30 mm (no pulley; the belt runs directly on the roller)
       └ the spool flange (outer rim) rests on the roller and is driven by friction
            └ filament ─ lever with elastic cord (switch) ─ printer
```

### 3. Feed control

- When the lever held by the elastic cord is pulled beyond a threshold, the switch closes and the motor pays out filament.
- After the switch opens, the motor runs 4000 more steps and stops.
- More filament is paid out than consumed. The elastic cord and the slack give more than 200 mm of buffer, which absorbs the pull of XY travel moves.
- The amount paid out changes with the remaining filament (winding diameter); the buffer absorbs this.

### 4. Drive geometry

| Item | Value | Basis |
|:--|:--|:--|
| Pulley pitch diameter | 12.73 mm | 20 teeth × 2 mm ÷ π |
| Belt pitch-line diameter on the roller | about 32.0 mm | 30 + 2 × (tooth height 0.75 + pitch line 0.254) |
| Angular reduction ratio | about 2.51 | 32.0 ÷ 12.73 (2.40 to 2.51 depending on how far the teeth sink into the urethane) |
| Roller surface travel per motor revolution | about 37.5 mm | 40 mm × 15 ÷ 16.0 |
| Steps per mm of roller surface | about 85.4 | 3200 steps/rev (1/16) ÷ 37.5 mm |

The spool flange diameter is constant, so the spool turns at a constant speed. The filament feed speed is "roller surface speed × (winding diameter ÷ flange diameter)" and changes with the remaining filament (e.g. 0.44 to 1.0 for a spool with a 180 mm flange and an 80 mm core).

### 5. Feed control values

The values of the 2023 firmware are kept. Because the old firmware called `move()` on every loop pass, its real motion differed from the settings. The new firmware reproduces that real motion with explicit values and only removes the speed jump at the moment the switch opens (verified in AVR simulation, see [tools/sim](../tools/sim/)).

| Item | Old setting | Old real motion | New firmware |
|:--|:--|:--|:--|
| Top speed (switch on) | 4000 steps/s | about 2,390 steps/s | 2400 steps/s (measured about 2,360) |
| Ramp-up acceleration | 2000 steps/s² | about 3,800 steps/s² | 4000 steps/s² |
| Right after the switch opens | – | jumps to about 3,900 steps/s | no jump |
| Deceleration after the switch opens | 2000 steps/s² | about 1,960 steps/s² | 2000 steps/s² |
| Feed after the switch opens | 4000 steps | 4000 steps | 4000 steps |
| Microstepping, current | 1/16, 600 mA RMS, stealthChop | same | same (identical TMC2130 register values) |

2400 steps/s is about 28 mm/s at the roller surface; 4000 steps is about 47 mm at the roller surface.

### 6. Protection

**Jam monitor (ATtiny85, independent of the main Pro Mini)**

- If the feed request (switch on) lasts 48 s without a break, a relay cuts the motor supply (VM) and the stop is latched. 48 s matches the effective value of the 2023 firmware.
- Off periods shorter than 20 ms (contact bounce) do not reset the timer.
- If the ATtiny85 itself hangs, the watchdog resets it and the stop is latched.
- While stopped, the output is high impedance and a pull-down resistor keeps the relay off.
- The reset switch (X3) resets both the Pro Mini and the ATtiny85 and clears the latched stop.
- On board rev.B, the external input (X5) is connected to the ATtiny85. When an external sensor reports a fault (LOW or broken wire), the motor supply is cut in the same way.

**Driver monitor (Pro Mini)**

- The TMC2130 configuration is read back and verified before the driver is enabled.
- The TMC2130 is checked every 500 ms. If the driver was reset (e.g. by a short interruption of the motor supply), it is reconfigured automatically.
- On overtemperature or short circuit, the driver is stopped and the stop is latched.
- If the feed request lasts 53 s, the software also stops the motor and latches (backup of the ATtiny85).

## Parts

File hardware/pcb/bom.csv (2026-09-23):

ref | qty | rev_a (as built) | rev_b | package | function | notes
ARDUINO1 | 1 | Arduino Pro Mini 5V 16MHz (ATmega328P) | same | Pro Mini footprint | Main controller | Mounted on pin sockets
U2 | 1 | ATtiny85-20PU | same | DIP-8 | Jam monitor | Mounted in a DIP-8 socket
TMC1 | 1 | BIGTREETECH TMC2130 module (SPI) | same | StepStick | Stepper driver | Plugged into J1/J2
U1 | 1 | NJM7805SDL | same | TO-252 | 5V regulator | Bottom side
K1 | 1 | Omron G6K-2P-Y DC5 | same | G6K-2P-Y | Motor supply relay | Coil 5 V (DC12 coil does not work on 5 V)
T1 | 1 | ROHM DTC144EKA | ROHM DTC123JKA | SMT3 (SC-59) | Relay driver | Bottom side. rev.B: built-in input resistor 2.2 kOhm gives drive margin
D1 | 1 | 1N4004 | same | DO-41 | Relay flyback diode
D2 | 1 | LED red | same | LED 5mm radial | Power indicator
D3 | 1 | LED green | same | LED 5mm radial | Feed request / status LED | rev.A: on D4 net. rev.B: driven from Pro Mini D8
C1 | 1 | 100uF >=16V aluminum electrolytic | same | Radial 3.5mm pitch dia 8mm | VM bulk capacitor (after relay)
C2 | 1 | 0.33uF ceramic | same | Radial 5.0mm pitch | 7805 input
C3 | 1 | 0.1uF ceramic | same | Radial 5.0mm pitch | 7805 output
PS1 | 1 | Littelfuse RXEF135 | same | Radial 5.08mm pitch | Resettable fuse (hold 1.35 A trip 2.7 A 72 V)
R1 | 1 | 10k | same | 0603 (rev.A) / 0805 (rev.B) | D4 pull-down | Bottom side
R2 | 1 | 680 | 2.2k | 0603 (rev.A) / 0805 (rev.B) | D2 series resistor | Top side. rev.A exceeds 0.1 W rating of a standard 0603 at 12 V
R3 | 1 | 10k | same | 0603 (rev.A) / 0805 (rev.B) | EXT_IN pull-down | rev.A: bottom side / rev.B: top side near U2
R4 | 1 | 150 | 470 | 0603 (rev.A) / 0805 (rev.B) | D3 series resistor | Bottom side. rev.B: limits D8 current to about 6 mA
R5 | 1 | - | 10k | 0805 | EXT_SENSE pull-down | rev.B only. Bottom side near X5
R6 | 1 | - | 10k | 0805 | EXT_SENSE series resistor to ATtiny85 PB4 | rev.B only. Bottom side near U2. Limits the input clamp current to about 0.65 mA at 12 V
J1 | 1 | Female header 1x8 | same | 2.54mm | TMC2130 power side
J2 | 1 | Female header 1x8 | same | 2.54mm | TMC2130 logic side
J3 | 1 | Female header 1x2 | same | 2.54mm | TMC2130 extra pins | Not connected
JP1 | 1 | Pin header 1x3 | same | 2.54mm | Relay bypass (2-3) | Normally open
JP2 | 1 | Pin header 1x3 | same | 2.54mm | rev.A: EXT_IN to +5V / rev.B: external sensor not used (1-2) | rev.A: do not fit with ATtiny85 installed
X1 | 1 | JST XH 2P | same | XH | Limit switch
X2 | 1 | JST XH 4P | same | XH | Stepper motor
X3 | 1 | JST XH 2P | same | XH | Reset switch | Resets Pro Mini and ATtiny85
X4 | 1 | JST XH 2P | same | XH | Power switch
X5 | 1 | JST XH 2P | same | XH | External input | rev.A: not used / rev.B: to ATtiny85 PB4 through R6
X6 | 1 | JST XH 2P | same | XH | 5 V output
X7 | 1 | DC jack 2.1mm | same | DC-21MM | 12 V input (center positive)
X9 | 1 | JST XH 3P | same | XH | Sensor input (alternative to X1)

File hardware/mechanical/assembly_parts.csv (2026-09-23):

qty_in_model | name_in_model | part | description_ja | description_en
2 | 17HS08-1004S | 17HS08-1004S | ステッピングモーター | Stepper motor
2 | gt2 | GT2 20T 6mm bore 5mm | タイミングプーリー | Timing pulley
2 | gt2_belt_188 | GT2 belt 188 | GT2無端ベルト 188mm | GT2 closed-loop belt 188 mm
2 | UMJ30-100 | UMJ30-100 | ウレタンローラー（ベアリング B698ZZ を2個ずつ含む） | Urethane roller (2 bearings B698ZZ each)
4 | U_idler_8 | U_idler_8 | アイドラー φ8mm用 | Idler for 8 mm shaft
2 | 8_shaft | RDSS8-300 | φ8シャフト 300mm | Shaft 8 mm x 300 mm
4 | SH8_MSM | SH8 MSM | シャフトホルダー φ8用 | Shaft holder for 8 mm
4 | NETW8 | NETW8 | E型止め輪 φ8用 | E-ring for 8 mm
2 | NFS5-2020-230 | NFS5-2020-230 | アルミフレーム 20x20x230mm | Aluminum extrusion 20x20x230 mm
10 | NFS5-2020-250 | NFS5-2020-250 | アルミフレーム 20x20x250mm | Aluminum extrusion 20x20x250 mm
2 | NFS5-2020-260 | NFS5-2020-260 | アルミフレーム 20x20x260mm | Aluminum extrusion 20x20x260 mm
2 | NFS5-2020-300 | NFS5-2020-300 | アルミフレーム 20x20x300mm | Aluminum extrusion 20x20x300 mm
28 | brkt_cheap | corner bracket | コーナーブラケット 20x20用 | Corner bracket for 20x20 extrusion
12 | HNTP5-5 | HNTP5-5 | アルミフレームナット M5 | T-nut M5 for 20x20 extrusion
1 | 20x300x3 | 20x300x3 | アクリル板 3mm（天面の固定部、ヒンジ取付け） | Acrylic plate 3 mm (fixed top strip for the hinges)
2 | 270x290_plate_wall | 270x290_plate_wall | アクリル板 3mm（側面） | Acrylic plate 3 mm (sides)
1 | 270x300_plate_wall | 270x300_plate_wall | アクリル板 3mm（正面図側） | Acrylic plate 3 mm (front view side)
1 | 270x300_plate_wall_out_hole | 270x300_plate_wall | アクリル板 3mm（正面図の反対側、穴あき） | Acrylic plate 3 mm (opposite the front view side; with hole)
1 | 270x300_plate_wall_roof | 270x300_plate_wall_roof | アクリル板 3mm（天面のふた） | Acrylic plate 3 mm (top lid)
1 | 290x300_plate_wall | 290x300_plate_wall | アクリル板 3mm（底面） | Acrylic plate 3 mm (bottom)
2 | hg_ts03 | HG-TS03 | トルクヒンジ（スガツネ） | Torque hinge (Sugatsune)
2 | SW_no_lever | - | ターコイズスイッチ | Switch for the tension lever
1 | LS_brkt_2 | Base_lever_R.stp | 自作部品 | Self-made part
1 | LS_brkt_2_MIR | Base_lever_L.stp | 自作部品 | Self-made part
1 | lever | lever_R.stp | 自作部品 | Self-made part
1 | lever_MIR | lever_L.stp | 自作部品 | Self-made part
2 | X End Stop Bracket | tri_Bracket.stp | 自作部品 | Self-made part
2 | MotorMount | MotorMount.stp | 自作部品 | Self-made part
2 | spool_tmc2130_b | - | 制御基板（hardware/pcb） | Control board (hardware/pcb)
8 | spacer_m3x10 | - | スペーサー M3 10mm | Spacer M3 10 mm
4 | JIS B 1176 - M5 x 16 | - | ねじ | Screw
4 | JIS B 1176 - M5 x 12 | - | ねじ | Screw
1 | JIS B 1176 - M5 x 10 | - | ねじ | Screw
2 | ISO 7380-1 - M5 x 10 | - | ねじ | Screw
4 | JIS B 1174 - M4 x 8 | - | ねじ | Screw
1 | JIS B 1176 - M3 x 16 | - | ねじ | Screw
4 | JIS B 1176 - M2.5 x 8 | - | ねじ | Screw
4 | JIS B 1181 - B M4 | - | ナット | Nut
8 | JIS B 1181 - M3 | - | ナット | Nut
2 | JIS B 1181 - A M3 | - | ナット | Nut
1 | JIS B 1256 - 3x7 | - | 座金 | Washer
2 | spool | - | フィラメントスプール（参考、部品ではない） | Filament spool (reference only)

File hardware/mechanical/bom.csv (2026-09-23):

qty | part_number | description_ja | description_en | notes
2 | 17HS08-1004S | ステッピングモーター | Stepper motor NEMA 17 (1.8 deg)
2 | GT2 20T 6mm bore 5mm | タイミングプーリー GT2 20歯 ベルト幅6mm用 穴径5mm | Timing pulley GT2 20T for 6 mm belt 5 mm bore | Added in 2026
2 | GT2 belt 188 | GT2無端ベルト 周長188mm 幅6mm | GT2 closed-loop belt 188 mm 6 mm wide | Runs directly on the urethane roller
2 | UMJ30-100 | ベアリング圧入ウレタンローラー 外径30mm | Urethane roller with bearings outer diameter 30 mm
4 | U_idler_8 | アイドラー φ8mm用U溝型 | U-groove idler for 8 mm shaft
2 | RDSS8-300 | φ8シャフト 300mm | Shaft 8 mm x 300 mm
4 | SH8 MSM | シャフトホルダー φ8用 | Shaft holder for 8 mm
4 | NETW8 | E型止め輪 φ8用 | E-ring for 8 mm
2 | NFS5-2020-230 | アルミフレーム 20x20x230mm | Aluminum extrusion 20x20x230 mm
10 | NFS5-2020-250 | アルミフレーム 20x20x250mm | Aluminum extrusion 20x20x250 mm
2 | NFS5-2020-260 | アルミフレーム 20x20x260mm | Aluminum extrusion 20x20x260 mm
2 | NFS5-2020-300 | アルミフレーム 20x20x300mm | Aluminum extrusion 20x20x300 mm
28 | corner bracket | コーナーブラケット 20x20用 | Corner bracket for 20x20 extrusion
1 | 20x300x3 | アクリル板 3mm | Acrylic plate 3 mm | Self-made: step/parts/20x300x3.stp
2 | 270x290_plate_wall | アクリル板 3mm | Acrylic plate 3 mm | Self-made: step/parts/270x290_plate_wall.stp
1 | 270x300_plate_wall | アクリル板 3mm | Acrylic plate 3 mm | Self-made: step/parts/270x300_plate_wall.stp
1 | 270x300_plate_wall_out_hole | アクリル板 3mm（穴あき） | Acrylic plate 3 mm (with hole) | Self-made: step/parts/270x300_plate_wall_out_hole.stp
1 | 270x300_plate_wall_roof | アクリル板 3mm | Acrylic plate 3 mm | Self-made: step/parts/270x300_plate_wall_roof.stp
1 | 290x300_plate_wall | アクリル板 3mm | Acrylic plate 3 mm | Self-made: step/parts/290x300_plate_wall.stp
2 | HG-TS03 | トルクヒンジ（スガツネ） | Torque hinge (Sugatsune)
1 | - | 取っ手（96mmピッチ） | Handle (96 mm pitch)
1 | - | トグルスイッチ | Toggle switch (power)
1 | - | DCジャック | DC jack
2 | - | ターコイズスイッチ | Switch for the tension lever | Part number to be added
2 | - | ごむひも | Elastic cord
2 | - | スイッチブラケット | Switch bracket | Self-made (3D printed): step/parts/Base_lever_L.stp and Base_lever_R.stp
2 | - | ゴムブラケット | Elastic cord bracket | Self-made (3D printed): step/parts/tri_Bracket.stp
2 | - | スイッチレバー | Switch lever | Self-made (3D printed): step/parts/lever_L.stp and lever_R.stp
2 | - | モーターマウント | Motor mount | Self-made: step/parts/MotorMount.stp
8 | - | スペーサー M3 10mm | Spacer M3 10 mm
as needed | - | アルミフレームナット M5 | T-nut M5 for 20x20 extrusion
as needed | - | ねじ M5 | Screw M5

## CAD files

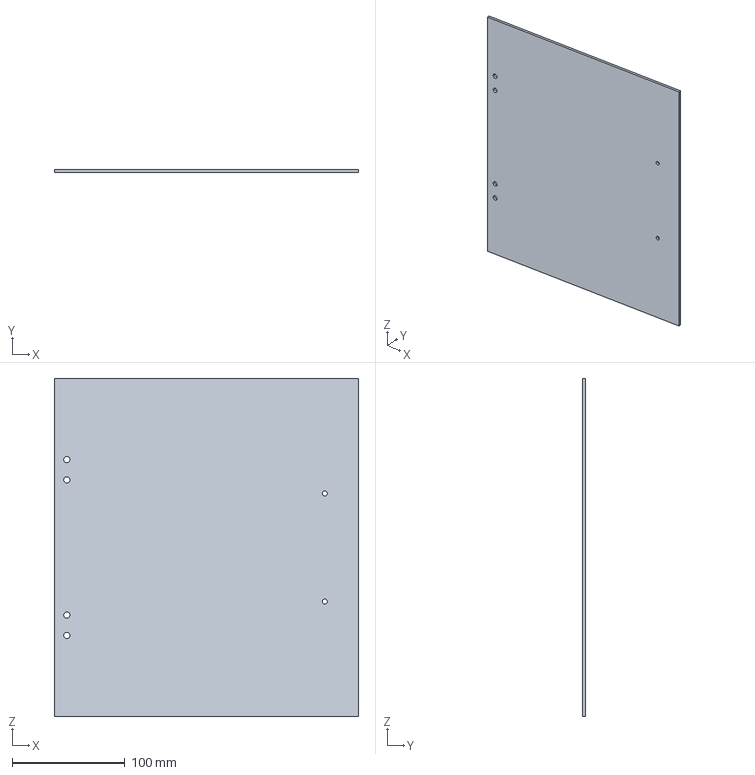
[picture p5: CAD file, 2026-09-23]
hardware/mechanical/step/parts/270x300_plate_wall_roof.stp
270.0 x 3.00 x 300.0 mm

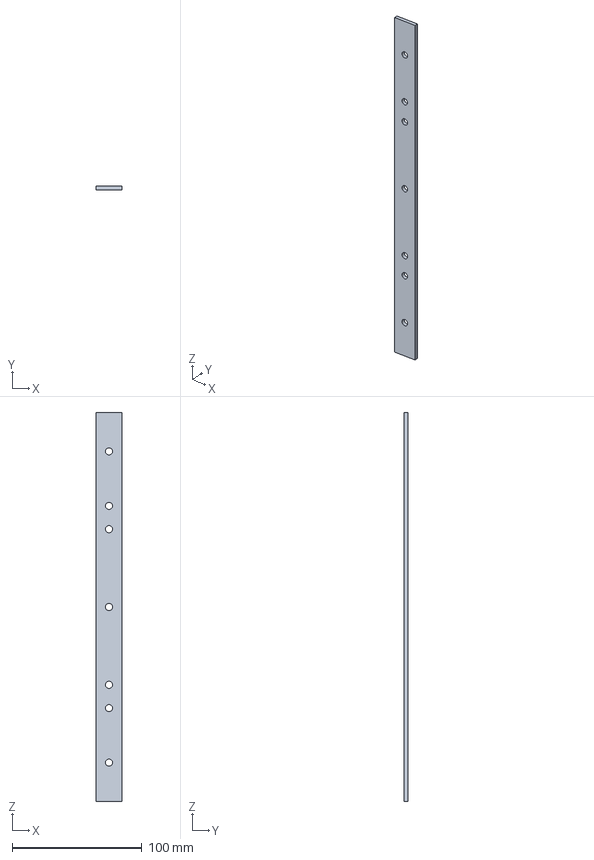
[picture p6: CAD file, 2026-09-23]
hardware/mechanical/step/parts/20x300x3.stp
20.0 x 3.00 x 300.0 mm

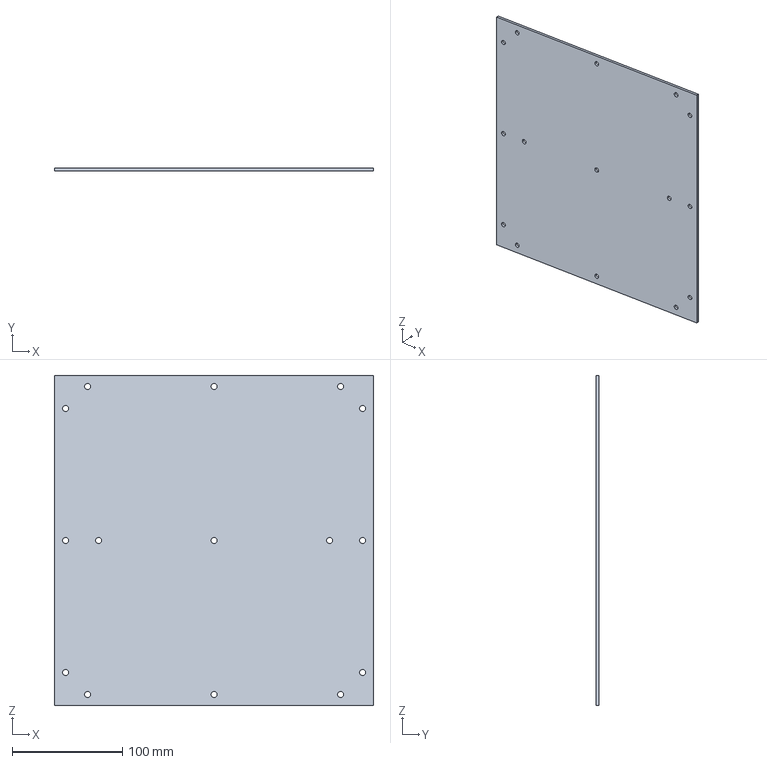
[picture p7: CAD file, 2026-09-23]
hardware/mechanical/step/parts/290x300_plate_wall.stp
290.0 x 3.00 x 300.0 mm

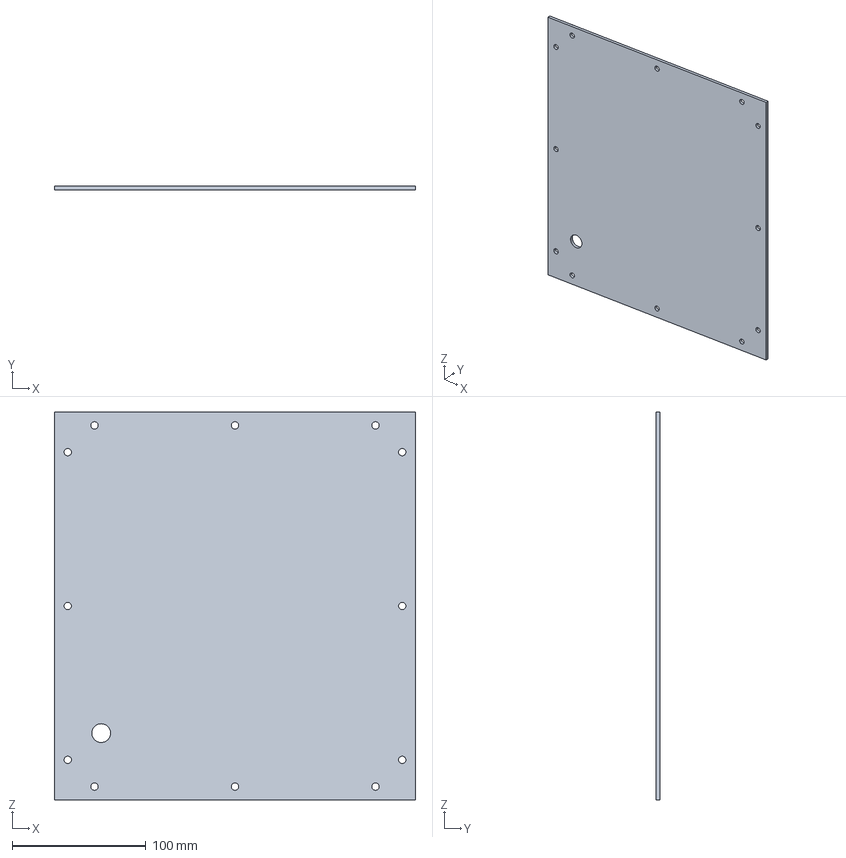
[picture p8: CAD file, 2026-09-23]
hardware/mechanical/step/parts/270x290_plate_wall.stp
270.0 x 3.00 x 290.0 mm

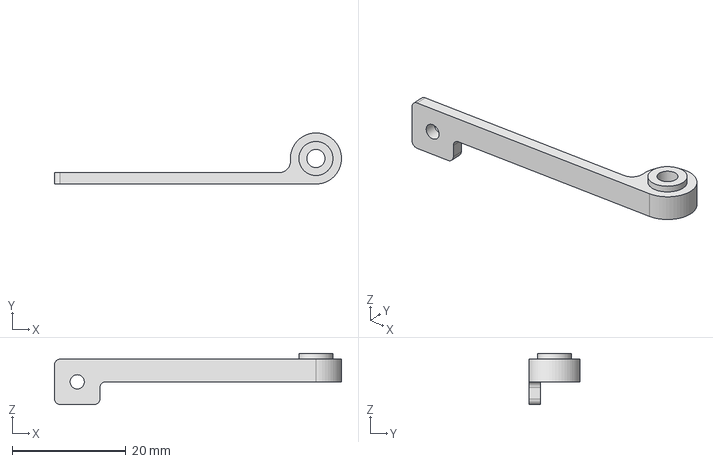
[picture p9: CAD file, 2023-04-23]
hardware/mechanical/step/parts/lever_L.stp
50.5 x 8.99 x 9.00 mm

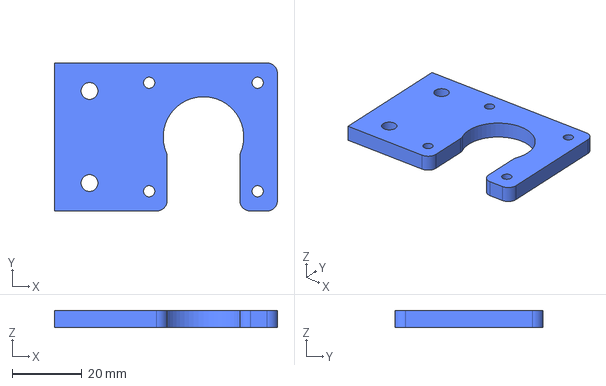
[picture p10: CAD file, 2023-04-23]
hardware/mechanical/step/parts/MotorMount.stp
63.7 x 42.3 x 5.00 mm

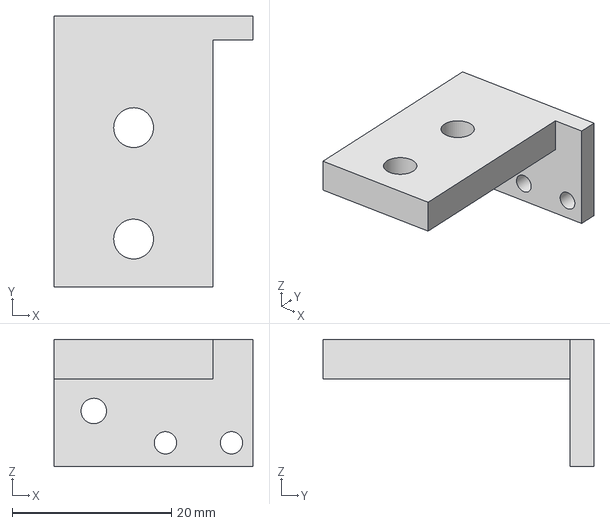
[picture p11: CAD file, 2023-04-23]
hardware/mechanical/step/parts/Base_lever_L.stp
25.0 x 34.0 x 16.0 mm

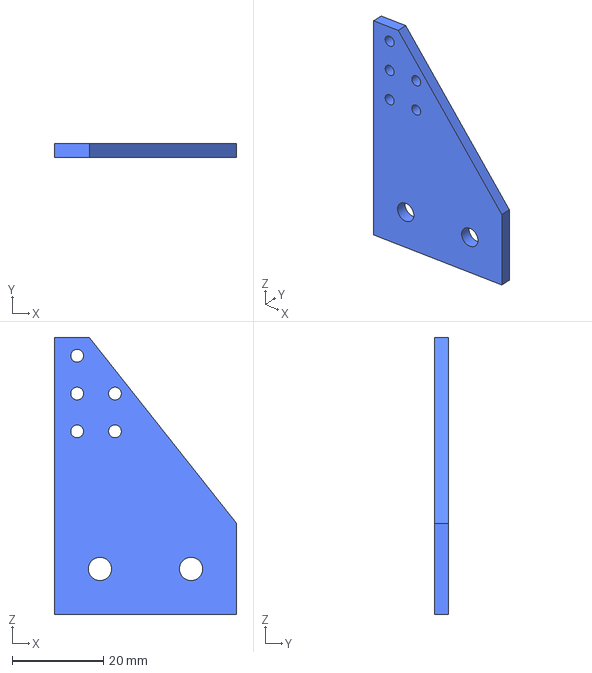
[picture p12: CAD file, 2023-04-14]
hardware/mechanical/step/parts/tri_Bracket.stp
40.0 x 3.00 x 60.8 mm

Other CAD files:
hardware/mechanical/step/parts/270x300_plate_wall.stp
hardware/mechanical/step/parts/270x300_plate_wall_out_hole.stp
hardware/mechanical/step/parts/Base_lever_R.stp
hardware/mechanical/step/parts/lever_R.stp

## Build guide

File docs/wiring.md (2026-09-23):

# 配線とピン割り当て / Wiring and pin assignment

[日本語](#日本語) | [English](#english)

基板: `hardware/pcb/eagle/spool_tmc2130_b`（rev.B）。rev.A のデータはタグ `pcb-rev.A` にあります。部品番号は rev.A と rev.B で共通です（R6 は rev.B のみ）。
Board: `hardware/pcb/eagle/spool_tmc2130_b` (rev.B). The rev.A files are in tag `pcb-rev.A`. Reference designators are the same on rev.A and rev.B (R6 exists on rev.B only).

---

## 日本語

### コネクタ（すべて JST XH、X7 を除く）

| コネクタ | 用途 | ピン |
|:--|:--|:--|
| X1 | リミットスイッチ（送り要求） | 1 = D4（送り要求）、2 = +5V。スイッチで 1-2 を短絡すると送り要求 |
| X9 | センサー入力（X1 の代わり） | 1 = +5V、2 = GND、3 = D4 |
| X2 | ステッピングモーター | 1 = B−、2 = B+、3 = A−、4 = A+ |
| X3 | リセットスイッチ | 1 = GND、2 = RST（Pro Mini と ATtiny85 の両方） |
| X4 | 電源スイッチ | 1 = DC ジャック側（PS1 経由）、2 = +12V |
| X5 | 外部入力 | 1 = +5V、2 = EXT_IN（rev.A）。rev.B では 2 = EXT_SENSE（ATtiny85 PB4） |
| X6 | 5V 出力 | 1 = +5V、2 = GND |
| X7 | DC ジャック 2.1mm | 12V 入力、センタープラス |

### ジャンパー

| ジャンパー | 短絡するピン | 働き | 通常 |
|:--|:--|:--|:--|
| JP1 | 2-3 | リレーをバイパスし、モーター電源（VM）を常時供給。ジャム保護は働かない | 開放 |
| JP2 | 1-2 | rev.A: EXT_IN を +5V に固定（リレー常時 ON、ジャム保護は働かない）。rev.B: 外部センサーを使わない設定 | rev.A: 開放 / rev.B: センサーなしなら短絡 |

rev.A で ATtiny85 を実装したまま JP2 を短絡しないでください。2023 年版ファームでは、ジャム停止時に ATtiny85 の出力と +5V が短絡します。

rev.B の X5 には、正常なときに2番を HIGH にするセンサーをつなぎます（例：1-2 間の常閉接点）。詳しくは [hardware/pcb/README.md](../hardware/pcb/README.md) を参照してください。

### Arduino Pro Mini（5V、16MHz）

| ピン | 接続 |
|:--|:--|
| D4 | 送り要求（X1 / X9、10kΩ プルダウン R1、HIGH = 送り） |
| D5 | TMC2130 DIR |
| D6 | TMC2130 STEP |
| D7 | TMC2130 EN（LOW で有効） |
| D8 | 状態表示 LED D3（rev.B のみ） |
| D10 / D11 / D12 / D13 | TMC2130 CS / SDI(MOSI) / SDO(MISO) / SCK |
| RST | X3、ATtiny85 RESET と共通 |
| VCC | +5V（NJM7805 から） |

### ATtiny85

| ピン | 信号 | 接続 |
|:--|:--|:--|
| 1 | PB5 / RESET | RST（X3、Pro Mini と共通） |
| 2 | PB3 | EXT_IN → T1 → リレー K1（HIGH でモーター電源 ON、10kΩ プルダウン R3） |
| 3 | PB4 | rev.A: 未接続 / rev.B: EXT_SENSE（X5 から R6 10kΩ 経由。X5 側を R5 10kΩ でプルダウン） |
| 4 | GND | GND |
| 5 | PB0 | 未接続 |
| 6 | PB1 | D4（送り要求） |
| 7 | PB2 | 未接続 |
| 8 | VCC | +5V |

### TMC2130 モジュール（BIGTREETECH TMC2130、SPI モード）

| ヘッダ | ピン |
|:--|:--|
| J1（電源側） | 1 = GND、2 = VIO(+5V)、3 = A+、4 = A−、5 = B+、6 = B−、7 = GND、8 = VM（リレー経由の 12V） |
| J2（ロジック側） | 1 = EN、2 = SDI、3 = SCK、4 = CS、5 = SDO、6 = 未接続（CLK）、7 = STEP、8 = DIR |
| J3 | 未接続 |

### 電源の流れ

DC ジャック X7（12V）→ PS1（RXEF135）→ 電源スイッチ X4 → +12V → NJM7805 → +5V。+12V → リレー K1（NO 接点）→ VM（C1 100µF）→ TMC2130。

---

## English

### Connectors (all JST XH except X7)

| Connector | Use | Pins |
|:--|:--|:--|
| X1 | Limit switch (feed request) | 1 = D4 (feed request), 2 = +5V. Shorting 1-2 requests feed |
| X9 | Sensor input (alternative to X1) | 1 = +5V, 2 = GND, 3 = D4 |
| X2 | Stepper motor | 1 = B−, 2 = B+, 3 = A−, 4 = A+ |
| X3 | Reset switch | 1 = GND, 2 = RST (both Pro Mini and ATtiny85) |
| X4 | Power switch | 1 = from DC jack (via PS1), 2 = +12V |
| X5 | External input | 1 = +5V, 2 = EXT_IN (rev.A). On rev.B, 2 = EXT_SENSE (ATtiny85 PB4) |
| X6 | 5 V output | 1 = +5V, 2 = GND |
| X7 | DC jack 2.1 mm | 12 V input, center positive |

### Jumpers

| Jumper | Pins | Function | Normal |
|:--|:--|:--|:--|
| JP1 | 2-3 | Bypasses the relay; motor supply (VM) always on. No jam protection | Open |
| JP2 | 1-2 | rev.A: ties EXT_IN to +5V (relay always on, no jam protection). rev.B: external sensor not used | rev.A: open / rev.B: fitted when no sensor is used |

On rev.A, do not fit JP2 while the ATtiny85 is installed. With the 2023 firmware, the ATtiny85 output is shorted to +5V when it stops the motor on a jam.

On rev.B, connect a sensor to X5 that drives pin 2 HIGH when everything is OK (for example a normally closed contact between pins 1 and 2). See [hardware/pcb/README.md](../hardware/pcb/README.md).

### Arduino Pro Mini (5 V, 16 MHz)

| Pin | Connection |
|:--|:--|
| D4 | Feed request (X1 / X9, 10 kΩ pull-down R1, HIGH = feed) |
| D5 | TMC2130 DIR |
| D6 | TMC2130 STEP |
| D7 | TMC2130 EN (active LOW) |
| D8 | Status LED D3 (rev.B only) |
| D10 / D11 / D12 / D13 | TMC2130 CS / SDI (MOSI) / SDO (MISO) / SCK |
| RST | X3, shared with ATtiny85 RESET |
| VCC | +5V (from NJM7805) |

### ATtiny85

| Pin | Signal | Connection |
|:--|:--|:--|
| 1 | PB5 / RESET | RST (X3, shared with the Pro Mini) |
| 2 | PB3 | EXT_IN → T1 → relay K1 (HIGH = motor supply on, 10 kΩ pull-down R3) |
| 3 | PB4 | rev.A: not connected / rev.B: EXT_SENSE (from X5 through R6 10 kΩ, pulled down by R5 10 kΩ on the X5 side) |
| 4 | GND | GND |
| 5 | PB0 | not connected |
| 6 | PB1 | D4 (feed request) |
| 7 | PB2 | not connected |
| 8 | VCC | +5V |

### TMC2130 module (BIGTREETECH TMC2130, SPI mode)

| Header | Pins |
|:--|:--|
| J1 (power side) | 1 = GND, 2 = VIO (+5V), 3 = A+, 4 = A−, 5 = B+, 6 = B−, 7 = GND, 8 = VM (12 V through the relay) |
| J2 (logic side) | 1 = EN, 2 = SDI, 3 = SCK, 4 = CS, 5 = SDO, 6 = not connected (CLK), 7 = STEP, 8 = DIR |
| J3 | not connected |

### Power path

DC jack X7 (12 V) → PS1 (RXEF135) → power switch X4 → +12V → NJM7805 → +5V. +12V → relay K1 (NO contact) → VM (C1 100 µF) → TMC2130.

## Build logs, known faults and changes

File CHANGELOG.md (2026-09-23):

# Changelog / 変更履歴

## Unreleased (2026 brush-up)

### Firmware / ファームウェア

- Main controller rewritten as `firmware/feeder_main` (was `arduino/TMC2130_spool.ino`).
  - TMC2130Stepper (deprecated) replaced by TMCStepper 0.7.3. TMC2130 register values are unchanged.
  - Feed values kept. The real motion of the old firmware (about 2,390 steps/s while requested, jump to about 3,900 steps/s when the request ended) is reproduced with explicit values, without the speed jump.
  - Driver configuration is read back and verified; the driver is reconfigured automatically after a reset (e.g. motor supply interruption); overtemperature or short circuit latches a stop.
  - Feed request input filter, backup jam timeout (53 s), serial status messages, status LED on D8 (board rev.B).
- Jam monitor rewritten as `firmware/jam_monitor_tiny85` (was `arduino/motor_emergency_stop_tiny85.ino`).
  - Fixed: the timer was reset only when the input fell within a 10 ms window (about 1/3 of releases were missed).
  - Timeout measured in real time (48 s, the effective value of the old firmware at 8 MHz).
  - Serial removed (conflicted with the input pin on ATTinyCore), watchdog added, high-impedance output on fault, external sensor input for board rev.B.
- Verified in AVR simulation (`tools/sim`) against the old binaries. CI compiles all variants.

- メイン制御を `firmware/feeder_main` に書き直し。TMCStepper へ移行（TMC2130 の設定値は同一）。送り値は維持し、旧版の実際の動きを再現しつつ停止時の速度の跳ね上がりを除去。ドライバの設定確認と自動再設定、異常時の停止保持、入力フィルタ、予備のジャム判定、シリアル出力、状態 LED を追加。
- ジャム監視を `firmware/jam_monitor_tiny85` に書き直し。計時のリセット漏れを修正、実時間 48 秒で判定、Serial 削除、ウォッチドッグ、停止時のハイインピーダンス出力、rev.B の外部入力に対応。
- 旧版バイナリとの比較を AVR シミュレーションで実施（`tools/sim`）。CI で全構成をコンパイル。

### Hardware / ハードウェア

- EAGLE files (the data used for fabrication) added under `hardware/pcb/eagle`. DesignSpark files removed (GND pour disconnected in the conversion; available in tag `v1.0-2023`).
- BOMs converted to CSV and corrected: relay G6K-2P-Y DC5, PS1 RXEF135, T1 DTC144EKA, timing pulley added.
- Control board rev.B designed in Autodesk Fusion and exported as EAGLE 9.7.0 files (rev.A is in tag `pcb-rev.A`): external sensor input EXT_SENSE to ATtiny85 PB4 through R6 10 kΩ with pull-down R5 10 kΩ, T1 → DTC123JKA, R2 → 2.2 kΩ, D3 driven from Pro Mini D8 with R4 → 470 Ω, chip resistors 0603 → 0805. Connectivity checked on the Gerber output. Schematic PDF added.
- Complete assembly STEP (`assy_top_dual.stp`) removed because it contained manufacturer 3D models of purchased parts. Replaced by an outline drawing (`docs/images/assembly_outline.png`) and a list of the parts in the assembly model (`hardware/mechanical/assembly_parts.csv`). Motor mount added to the mechanical BOM.
- STEP files of the six self-made acrylic plates added to `hardware/mechanical/step/parts` (extracted unchanged from the assembly model). Mechanical BOM quantities corrected to the assembly model.

- 発注に使った EAGLE データを追加。DesignSpark データは削除（変換時に GND ベタが外れていたため。タグ `v1.0-2023` で参照可能）。
- 部品表を CSV にして修正（リレー DC5、PS1 RXEF135、T1 DTC144EKA、タイミングプーリー追加）。
- 制御基板 rev.B を Autodesk Fusion で作成し、EAGLE 9.7.0 形式で書き出し（rev.A はタグ `pcb-rev.A`）。外部センサー入力 EXT_SENSE（R6 10kΩ 経由で ATtiny85 PB4、R5 10kΩ でプルダウン）、T1 を DTC123JKA、R2 を 2.2kΩ、D3 を Pro Mini D8 で駆動（R4 470Ω）、チップ抵抗を 0603 から 0805 に変更。ガーバー出力で接続を確認。回路図 PDF を追加。
- 購入部品のメーカー製 3D モデルを含んでいた全体組立の STEP（`assy_top_dual.stp`）を削除し、組立外形図と、組立モデルの部品と数量の一覧に置き換え。機構の部品表にモーターマウントを追加。
- 自作のアクリル板6種の STEP を `hardware/mechanical/step/parts` に追加（組立モデルから形状を変えずに抽出）。機構の部品表の数量を組立モデルに合わせて修正。

### Repository / リポジトリ

- New layout (`firmware/`, `hardware/`, `docs/`, `tools/`), bilingual README, documentation of principle and wiring, licenses (CERN-OHL-S-2.0 / GPL-3.0-or-later / CC BY-SA 4.0), images stored in the repository.
- フォルダ構成を整理、README を日英併記、原理と配線の文書、ライセンス、画像をリポジトリ内に保存。

## v1.0-2023

- Original upload (April 2023). / 2023年4月の最初の公開。

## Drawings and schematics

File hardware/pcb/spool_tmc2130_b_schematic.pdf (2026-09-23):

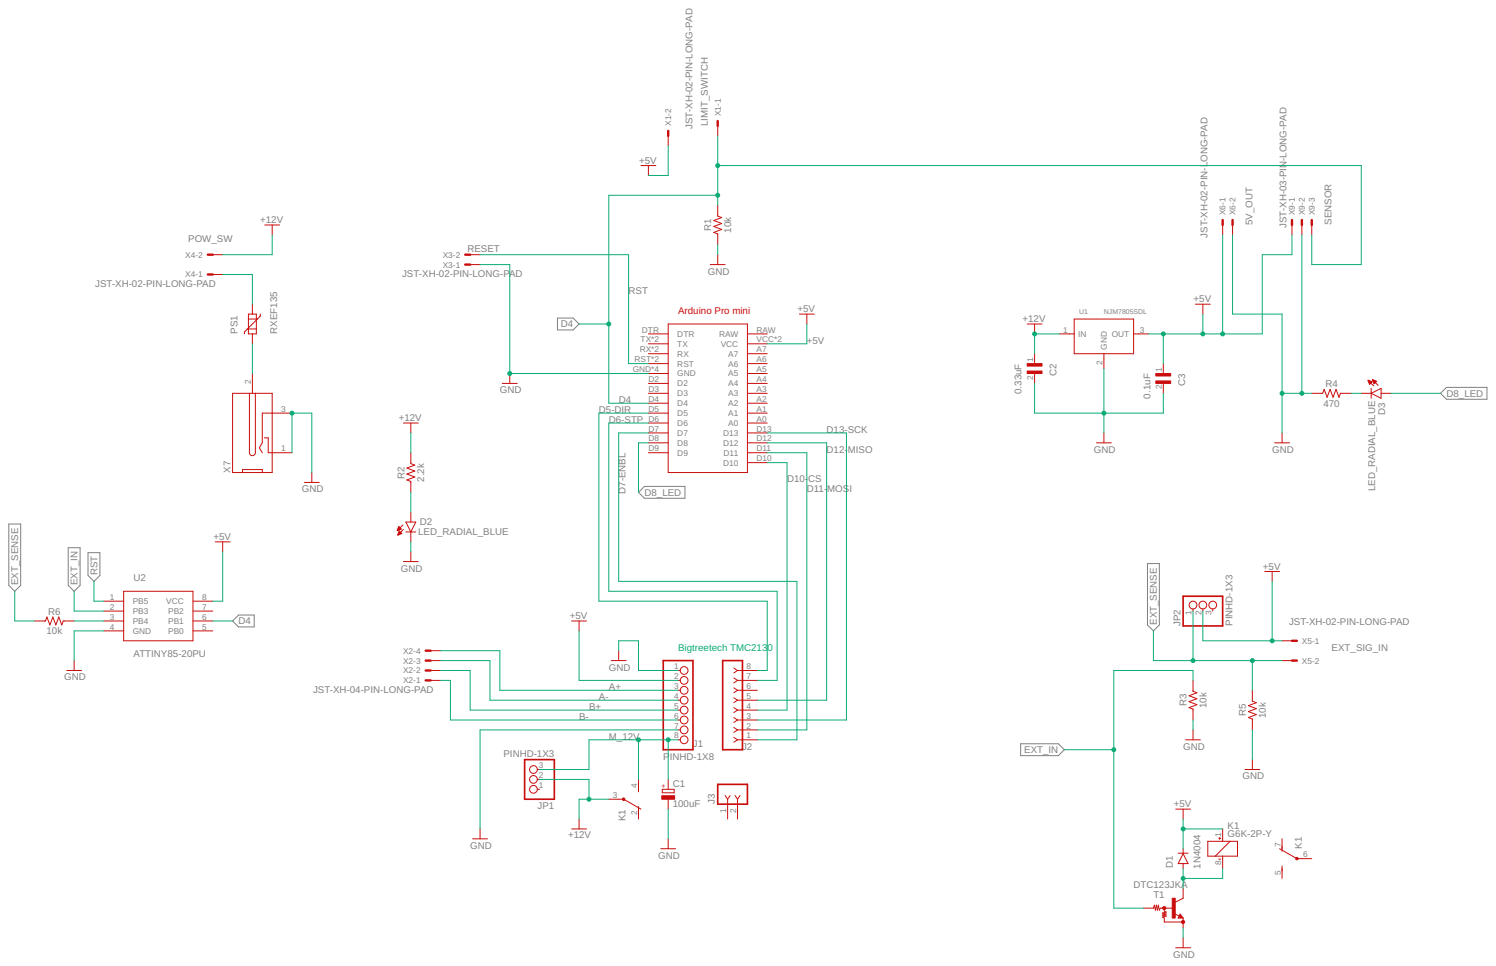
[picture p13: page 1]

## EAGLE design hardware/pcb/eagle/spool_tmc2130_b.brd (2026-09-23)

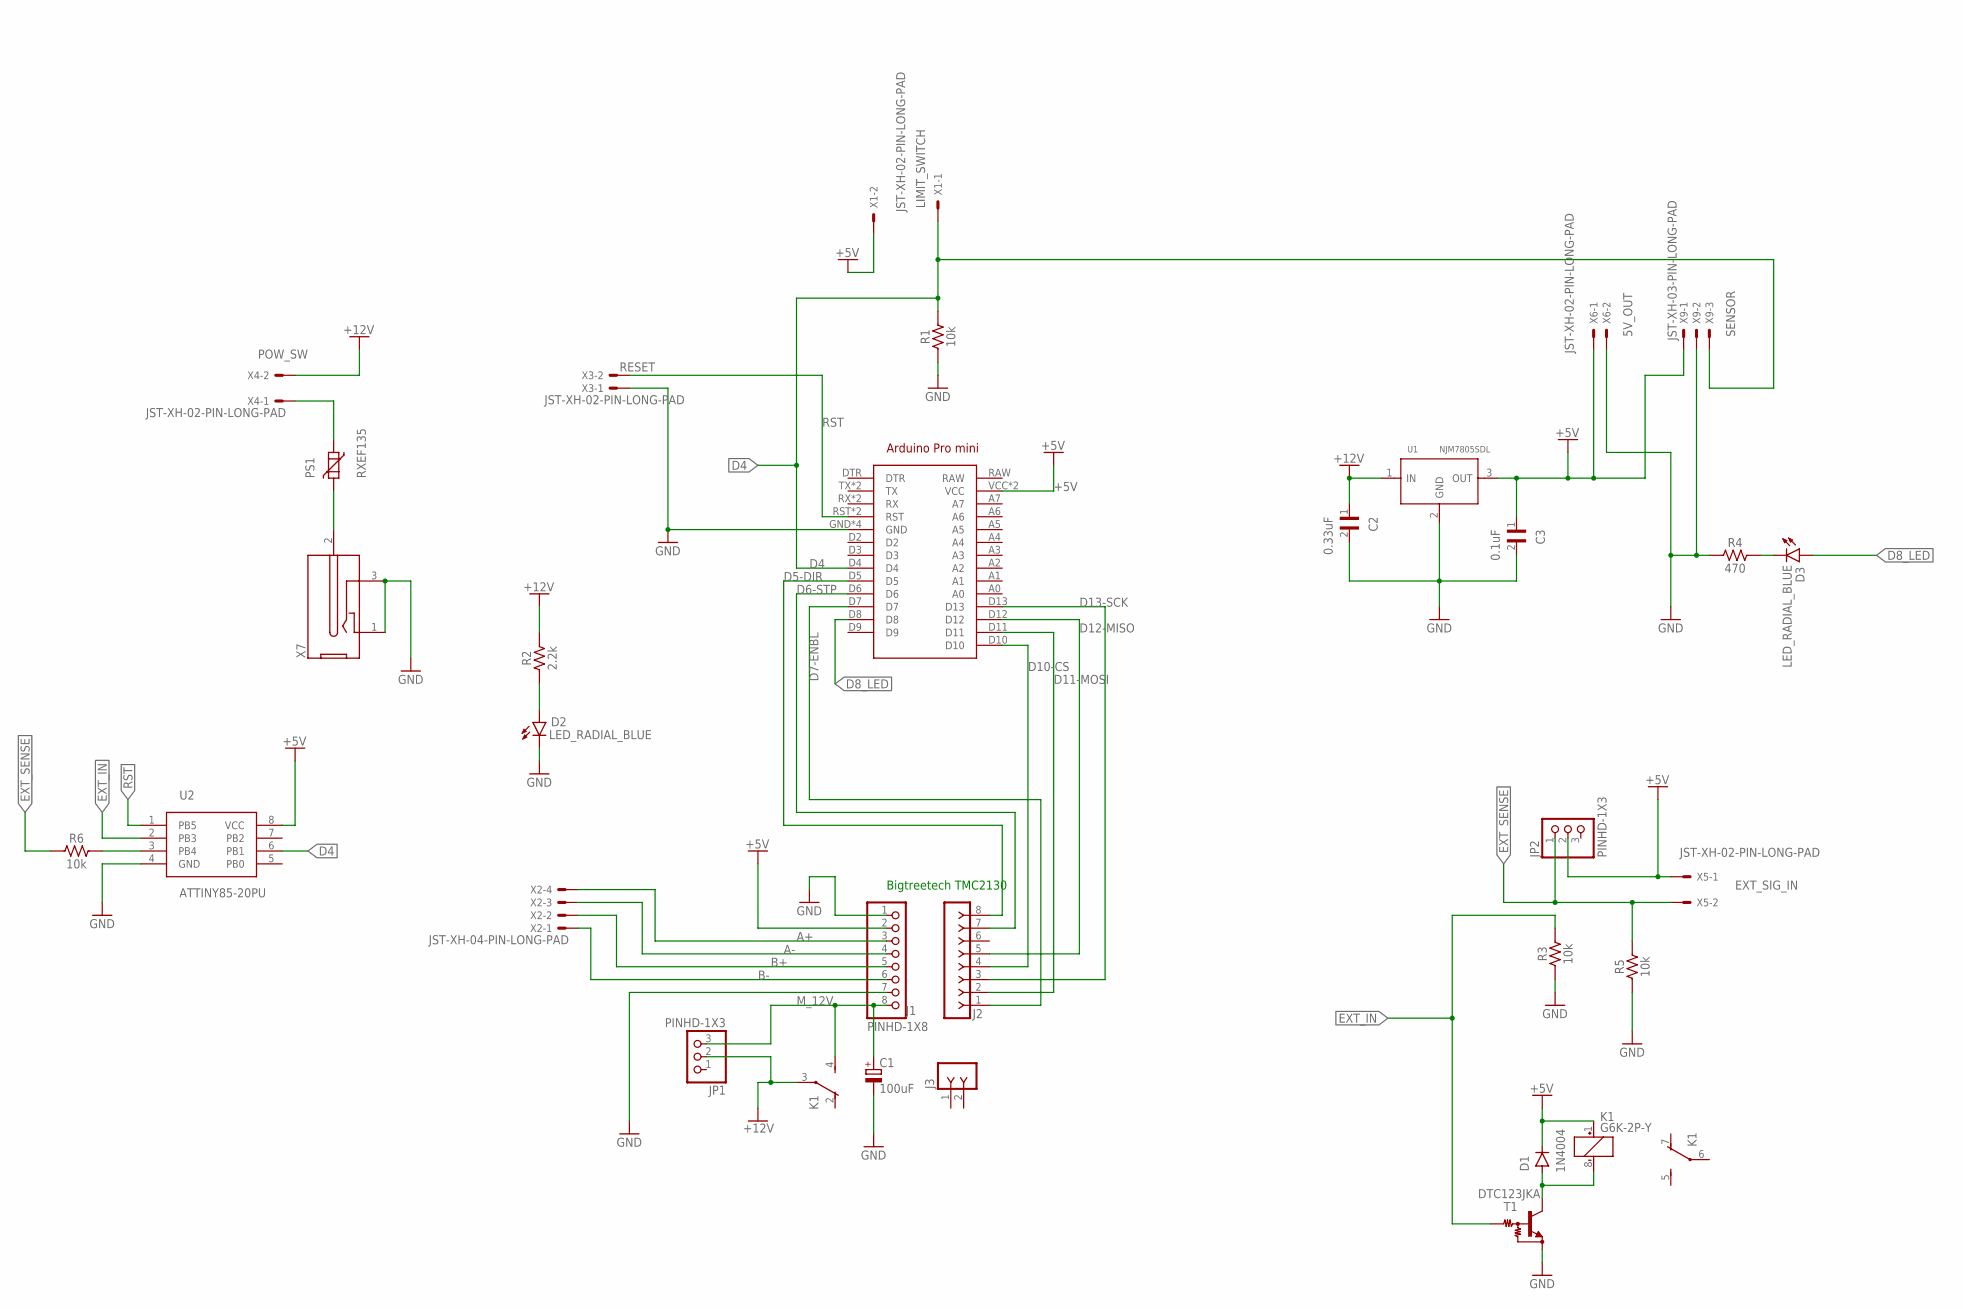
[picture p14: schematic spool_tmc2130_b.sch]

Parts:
ARDUINO1: ARDUINO_PRO_MINI
C1: 100uF; E3,5-8
C2: 0.33uF; CAP_RDER73A103K2K1H03B
C3: 0.1uF; CAP_RDER73A103K2K1H03B
D1: 1N4004; DO-41
D2, D3: LED_RADIAL_BLUE; LEDRD254W60D565H860B_B
J1: PINHD-1X8; 1X08
J2: F-1X08-SIP-100-40; SIP-100-08-40
J3: F-1X02-SIP-100-32; SIP-100-02-32
JP1, JP2: PINHD-1X3; 1X03
K1: G6K-2P-Y
PS1: RXEF135; SO5K11
R1, R3, R5, R6: 10k; RESC2012X65
R2: 2.2k; RESC2012X65
R4: 470; RESC2012X65
T1: DTC123JKA; SC59-BEC
U1: NJM7805SDL; TO-252
U2: ATTINY85-20PU; PDIP-8
X1, X3, X4, X5, X6: JST-XH-02-PIN-LONG-PAD; JST-XH-02-PACKAGE-LONG-PAD
X2: JST-XH-04-PIN-LONG-PAD; JST-XH-04-PACKAGE-LONG-PAD
X7: DC-2.1MM-5MM; DC-21MM
X9: JST-XH-03-PIN-LONG-PAD; JST-XH-03-PACKAGE-LONG-PAD

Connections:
+5V: ARDUINO1.VCC, ARDUINO1.VCC@1 (VCC), C3.1, D1.C, J1.2, JP2.2, K1.1 (+), U1.3 (OUT), U2.8 (VCC), X1.2, X5.1, X6.1, X9.1
+12V: C2.1, JP1.2, K1.3, R2.2, U1.1 (IN), X4.2
A+: J1.3, X2.4
A-: J1.4, X2.3
B+: J1.5, X2.2
B-: J1.6, X2.1
D4: ARDUINO1.D4, R1.2, U2.6 (PB1), X1.1, X9.3
D5-DIR: ARDUINO1.D5, J2.8
D6-STP: ARDUINO1.D6, J2.7
D7-ENBL: ARDUINO1.D7, J2.1
D8_LED: ARDUINO1.D8, D3.1 (A)
D10-CS: ARDUINO1.D10, J2.4
D11-MOSI: ARDUINO1.D11, J2.2
D12-MISO: ARDUINO1.D12, J2.5
D13-SCK: ARDUINO1.D13, J2.3
EXT_IN: R3.2, T1.B, U2.2 (PB3)
EXT_SENSE: JP2.1, R5.2, R6.1, X5.2
GND: ARDUINO1.GND, ARDUINO1.GND@1 (GND), ARDUINO1.GND@2 (GND), ARDUINO1.GND@3 (GND), C1.-, C2.2, C3.2, D2.2 (C), J1.1, J1.7, R1.1, R3.1, R4.1, R5.1, T1.E, U1.2 (GND), U2.4 (GND), X3.1, X6.2, X7.1, X7.3 (2), X9.2
M_12V: C1.+, J1.8, JP1.3, K1.4 (S)
unnamed: R6.2, U2.3 (PB4)
unnamed: D3.2 (C), R4.2
unnamed: PS1.1, X4.1
unnamed: PS1.2, X7.2 (3)
unnamed: D2.1 (A), R2.1
unnamed: D1.A, K1.8 (-), T1.C
RST: ARDUINO1.RST, ARDUINO1.RST@1 (RST), U2.1 (PB5), X3.2

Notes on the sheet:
Bigtreetech TMC2130

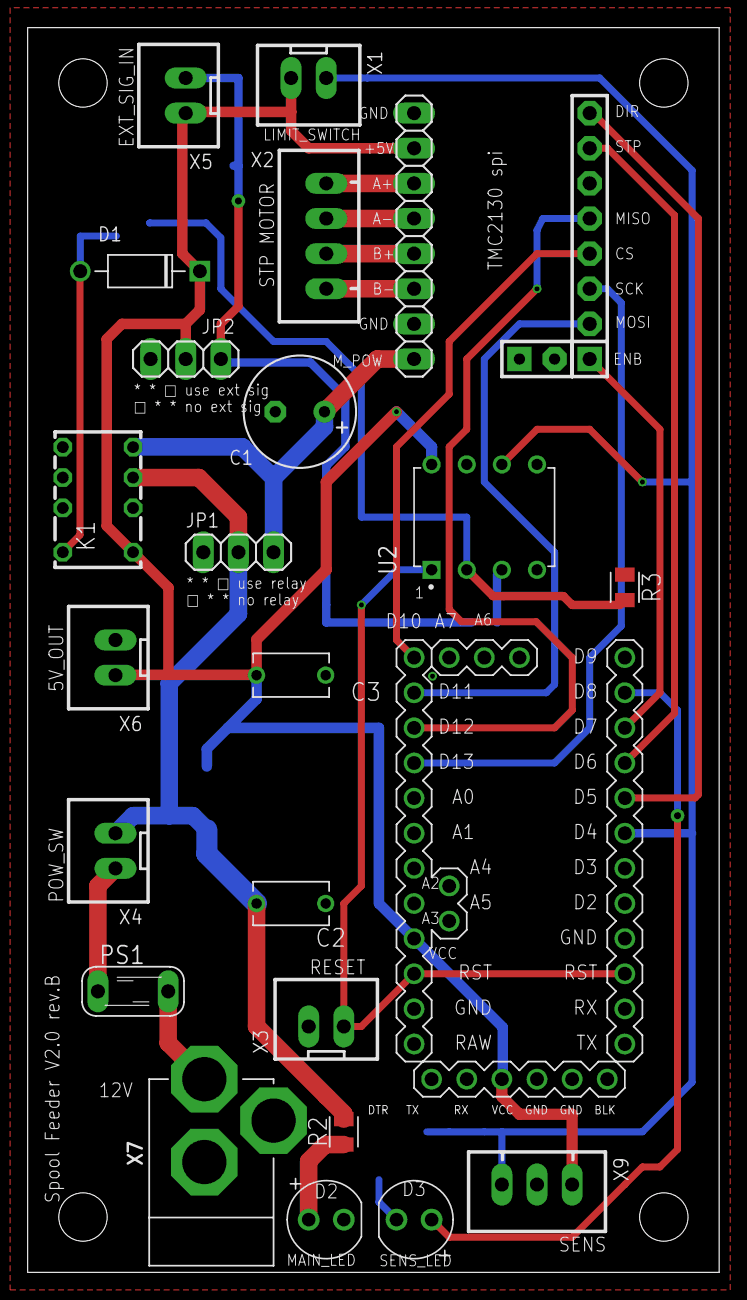
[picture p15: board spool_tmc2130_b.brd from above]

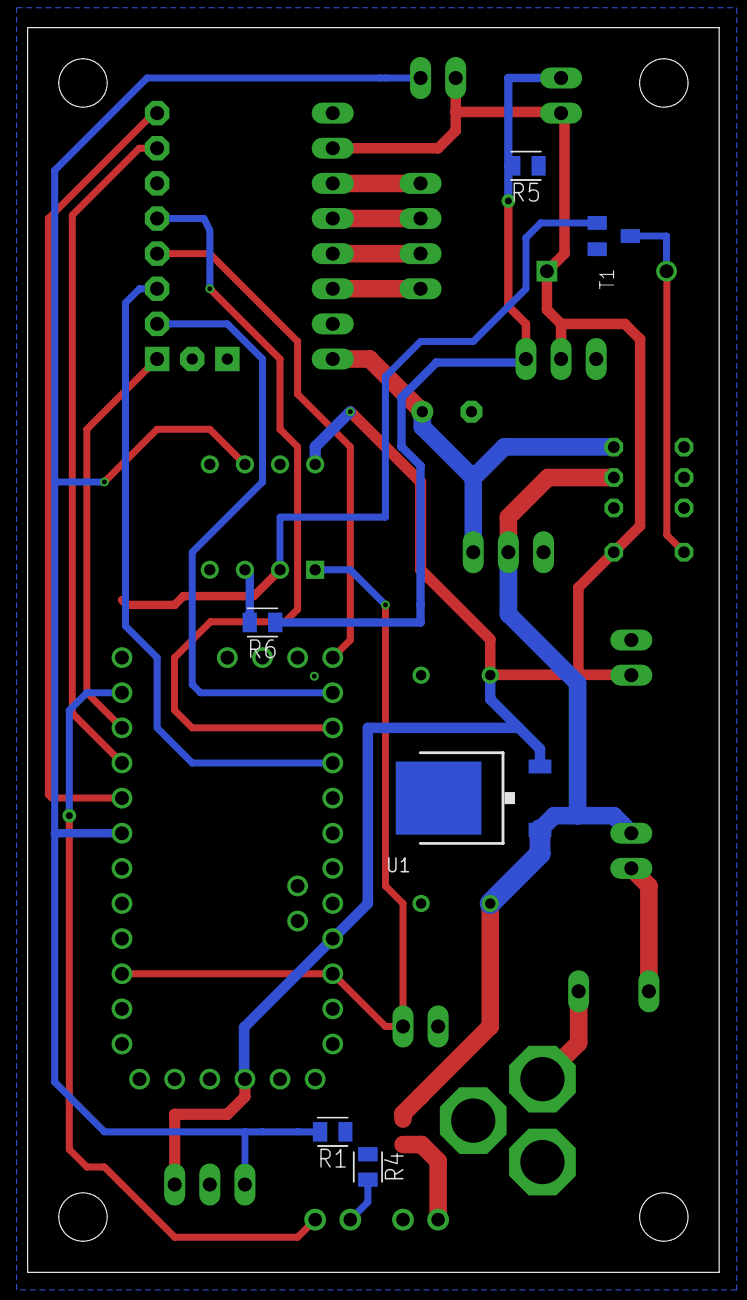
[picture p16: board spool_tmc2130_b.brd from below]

Board: 2 copper layers, 50.0 x 90.0 mm, 31 parts (6 on the bottom side), 26 nets.

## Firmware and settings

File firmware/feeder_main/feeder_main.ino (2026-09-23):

// SPDX-License-Identifier: GPL-3.0-or-later
// Copyright (C) 2023-2026 atsukita1969
// https://github.com/atsukita1969/filament-spool-feeder
/*
 * feeder_main - filament spool feeder, main controller
 *
 * Target : Arduino Pro or Pro Mini, ATmega328P (5V, 16 MHz)
 * Libs   : TMCStepper 0.7.3, AccelStepper 1.64
 *
 * While the feed request (D4) is HIGH the spool is driven; after it goes LOW the motor
 * runs FEED_STEPS more and stops. Feed values are unchanged from TMC2130_spool.ino (2023);
 * the speed jump that the old code made when the request ended is removed (see config.h).
 *
 * Changes from TMC2130_spool.ino
 *   - TMC2130Stepper (deprecated) -> TMCStepper. Resulting TMC2130 register values are identical.
 *   - The driver configuration is read back and verified; the driver is enabled only after that.
 *   - The TMC2130 is checked every DRIVER_CHECK_MS. If it was reset (GSTAT.reset, e.g. after the
 *     motor supply was interrupted) or stopped responding, it is reconfigured automatically.
 *   - The feed request is filtered (INPUT_FILTER_MS).
 *   - Motion profile set explicitly: same top speed and ramps as the old firmware really had,
 *     but no speed jump when the request ends.
 *   - Backup jam timeout in software (in addition to the ATtiny85), latched until reset.
 *   - Status messages on the serial port (115200 baud, FTDI header of the Pro Mini).
 *   - Status LED on D8 (board rev.B): ON = feed requested, slow blink = motor driver not ready
 *     (motor supply cut, e.g. by the ATtiny85 jam monitor), fast blink = fault latched.
 *   - Removed: while(!Serial) (no effect on the ATmega328P), unused defines and variables.
 */
#include <SPI.h>
#include <TMCStepper.h>
#include <AccelStepper.h>
#include "config.h"

// Gives access to the library's shadow registers for read-back verification.
class Tmc2130 : public TMC2130Stepper {
 public:
  Tmc2130(uint16_t cs, float rs) : TMC2130Stepper(cs, rs) {}
  uint32_t expectedGCONF() const { return GCONF_register.sr; }
  uint32_t expectedCHOPCONF() const { return CHOPCONF_register.sr; }
};

static Tmc2130 driver(PIN_CS, R_SENSE);
static AccelStepper stepper(AccelStepper::DRIVER, PIN_STEP, PIN_DIR);

static bool driverReady = false;
static bool faultLatched = false;
static bool feedRequest = false;      // filtered request
static bool rawPrev = false;
static uint32_t rawChangeMs = 0;
static uint32_t requestSinceMs = 0;
static uint32_t lastCheckMs = 0;
static volatile uint8_t *reqPort;     // fast read of the request pin (keeps the loop as short as the old one)
static uint8_t reqMask;
#if MOTION_MODE == MOTION_EXPLICIT
static bool accelUp = false;          // true while the ramp-up acceleration is set
#endif
static bool ledOn = false;

// Write the configuration and verify it by reading back. Returns true when the driver is usable.
static bool configureDriver() {
  driver.begin();                                  // GCONF, CHOPCONF, COOLCONF, PWMCONF, IHOLD_IRUN, toff=8, tbl=1
  driver.rms_current(RUN_CURRENT_MA, HOLD_MULT);
  driver.en_pwm_mode(true);                        // stealthChop  (old: stealthChop(1))
  driver.pwm_autoscale(true);                      //              (old: stealth_autoscale(1))
  driver.microsteps(MICROSTEPS);

  if (driver.version() != TMC2130_VERSION) return false;
  if (driver.GCONF() != driver.expectedGCONF()) return false;
  if (driver.CHOPCONF() != driver.expectedCHOPCONF()) return false;
  (void)driver.GSTAT();                            // clear the reset flag (read clears)
  return true;
}

static void setDriverReady(bool ready, const __FlashStringHelper *why) {
  if (ready == driverReady) return;
  driverReady = ready;
  if (ready && !faultLatched) {
    stepper.enableOutputs();
  } else if (!ready) {
    stepper.disableOutputs();
  }
  Serial.println(why);
}

static void latchFault(const __FlashStringHelper *why) {
  faultLatched = true;
  stepper.setCurrentPosition(stepper.currentPosition());   // stop at once
  stepper.disableOutputs();
  Serial.println(why);
}

static void serviceDriver(uint32_t now) {
  if (now - lastCheckMs < DRIVER_CHECK_MS) return;
  lastCheckMs = now;
  if (driverReady) {
    const uint8_t gstat = driver.GSTAT();          // bit0 reset, bit1 drv_err, bit2 uv_cp (read clears)
    if (gstat & 0x02) {
      setDriverReady(false, F("TMC2130: driver error"));
      latchFault(F("FAULT: TMC2130 overtemperature or short circuit. Latched until reset."));
    } else if (gstat & 0x05) {
      setDriverReady(false, F("TMC2130: reset / undervoltage detected (motor supply interrupted?)"));
    } else if (driver.version() != TMC2130_VERSION) {
      setDriverReady(false, F("TMC2130: not responding"));
    }
  }
  if (!driverReady && !faultLatched && configureDriver()) {
    setDriverReady(true, F("TMC2130: configured and verified"));
  }
}

static void updateRequest(uint32_t now) {
  const bool raw = (*reqPort & reqMask) != 0;
  if (raw != rawPrev) {
    rawPrev = raw;
    rawChangeMs = now;
  } else if (raw != feedRequest && (now - rawChangeMs) >= INPUT_FILTER_MS) {
    feedRequest = raw;
    if (raw) requestSinceMs = now;
  }
}

// Status LED. Bit tests on millis() keep this cheap enough for every loop pass.
static void updateLed(uint32_t now) {
  bool on;
  if (faultLatched) {
    on = (now >> 7) & 1;               // fast blink, 128 ms on / 128 ms off
  } else if (!driverReady) {
    on = (now >> 9) & 1;               // slow blink, 512 ms on / 512 ms off
  } else {
    on = feedRequest;
  }
  if (on != ledOn) {
    ledOn = on;
    digitalWrite(PIN_LED, on ? HIGH : LOW);
  }
}

void setup() {
  Serial.begin(SERIAL_BAUD);
  Serial.println(F("feeder_main start"));

  pinMode(PIN_LED, OUTPUT);
  digitalWrite(PIN_LED, LOW);
  pinMode(PIN_REQUEST, INPUT);                     // external pull-down R1
  reqPort = portInputRegister(digitalPinToPort(PIN_REQUEST));
  reqMask = digitalPinToBitMask(PIN_REQUEST);
  SPI.begin();

  stepper.setMaxSpeed(MOTION_MODE == MOTION_LEGACY ? MAX_SPEED : EXPLICIT_MAX_SPEED);
  stepper.setAcceleration(MOTION_MODE == MOTION_LEGACY ? ACCELERATION : EXPLICIT_DECEL);
  stepper.setEnablePin(PIN_EN);                    // driver stays disabled here
  stepper.setPinsInverted(DIR_INVERT, false, true);
  stepper.disableOutputs();

  lastCheckMs = millis() - DRIVER_CHECK_MS;        // first check right away
  serviceDriver(millis());
}

void loop() {
  const uint32_t now = millis();
  updateRequest(now);

  if (feedRequest && !faultLatched) {
    if (BACKUP_TIMEOUT_MS && (now - requestSinceMs) >= BACKUP_TIMEOUT_MS) {
      latchFault(F("FAULT: feed request active too long (jam?). Latched until reset."));
    } else if (driverReady) {
#if MOTION_MODE == MOTION_LEGACY
      stepper.move(FEED_STEPS);                    // same call pattern as the 2023 firmware
      stepper.enableOutputs();
#else
      if (!accelUp) {
        stepper.setAcceleration(EXPLICIT_ACCEL_UP);
        accelUp = true;
      }
      if (stepper.distanceToGo() < FEED_STEPS - RETARGET_STEPS) stepper.move(FEED_STEPS);
#endif
    }
  }
#if MOTION_MODE == MOTION_EXPLICIT
  if (!feedRequest && accelUp) {                   // request ended
    if (driverReady && !faultLatched) stepper.move(FEED_STEPS);   // exactly FEED_STEPS more, as before
    stepper.setAcceleration(EXPLICIT_DECEL);       // decelerate with the original value
    accelUp = false;
  }
#endif
  stepper.run();
  serviceDriver(now);
  updateLed(now);
}

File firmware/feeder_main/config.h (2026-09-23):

// SPDX-License-Identifier: GPL-3.0-or-later
// Copyright (C) 2023-2026 atsukita1969
// https://github.com/atsukita1969/filament-spool-feeder
// config.h - settings for feeder_main (Arduino Pro Mini 5V 16 MHz + TMC2130 SPI)
#pragma once
#include <stdint.h>

// ---- Pin assignment (schematic spool_tmc2130_b) ----
constexpr uint8_t PIN_REQUEST = 4;    // D4: feed request (X1 limit switch / X9 sensor), HIGH = feed, ext. pull-down R1
constexpr uint8_t PIN_DIR     = 5;    // D5: TMC2130 DIR
constexpr uint8_t PIN_STEP    = 6;    // D6: TMC2130 STEP
constexpr uint8_t PIN_EN      = 7;    // D7: TMC2130 EN (active LOW)
constexpr uint8_t PIN_CS      = 10;   // D10: TMC2130 CS  (D11 MOSI, D12 MISO, D13 SCK = hardware SPI)
constexpr uint8_t PIN_LED     = 8;    // D8: status LED D3 via R4 (board rev.B; not connected on rev.A)

// ---- Feed control: same values as the 2023 firmware (TMC2130_spool.ino) ----
constexpr long  FEED_STEPS   = 4000;  // 50 * 80: steps fed after the request ends
constexpr float MAX_SPEED    = 4000;  // steps/s  (setMaxSpeed)
constexpr float ACCELERATION = 2000;  // steps/s^2 (setAcceleration)
constexpr bool  DIR_INVERT   = true;  // setPinsInverted(true, false, true)

// Motion call pattern.
//   MOTION_EXPLICIT : (default) the motion profile is set explicitly. The values below reproduce what
//                     the 2023 firmware actually did (measured in simulation), without its speed jump
//                     at the moment the request ends.
//   MOTION_LEGACY   : identical call pattern to the 2023 firmware (move() and enableOutputs() on every
//                     loop pass). Kept for comparison only. The real speed is then limited by loop time
//                     (about 2390 steps/s) and jumps to about 3900 steps/s when the request ends.
#define MOTION_LEGACY   1
#define MOTION_EXPLICIT 2
#ifndef MOTION_MODE                   // can be overridden with -DMOTION_MODE=1
#define MOTION_MODE     MOTION_EXPLICIT
#endif
constexpr float EXPLICIT_MAX_SPEED = 2400;               // steps/s   (2023 firmware: about 2390 while requested)
constexpr float EXPLICIT_ACCEL_UP  = 2 * ACCELERATION;   // steps/s^2 while requested (2023 firmware: about 3800)
constexpr float EXPLICIT_DECEL     = ACCELERATION;       // steps/s^2 after the request ends (2023 firmware: about 1960)
constexpr long  RETARGET_STEPS     = 32;                 // re-extend the target when it has shrunk by this much

// ---- TMC2130: same values as the 2023 firmware ----
constexpr float    R_SENSE        = 0.11f;  // ohm (library default of the old code)
constexpr uint16_t RUN_CURRENT_MA = 600;    // RMS
constexpr float    HOLD_MULT      = 0.5f;   // hold current = run current * 0.5
constexpr uint16_t MICROSTEPS     = 16;
constexpr uint8_t  TMC2130_VERSION = 0x11;  // IOIN.VERSION of the TMC2130

// ---- Robustness (new) ----
constexpr uint16_t INPUT_FILTER_MS   = 5;       // request must be stable this long
constexpr uint16_t DRIVER_CHECK_MS   = 500;     // TMC2130 health check period
constexpr uint32_t BACKUP_TIMEOUT_MS = 53000UL; // software jam timeout (backup of the ATtiny85, 48 s); 0 = off
constexpr uint32_t SERIAL_BAUD       = 115200;

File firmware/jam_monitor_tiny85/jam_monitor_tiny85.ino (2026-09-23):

// SPDX-License-Identifier: GPL-3.0-or-later
// Copyright (C) 2023-2026 atsukita1969
// https://github.com/atsukita1969/filament-spool-feeder
/*
 * jam_monitor_tiny85 - independent jam watchdog for the filament spool feeder
 *
 * Target : ATtiny85, ATTinyCore (board "ATtiny25/45/85 (No bootloader)"),
 *          Clock 8 MHz internal, B.O.D. 2.7 V. Run "Burn Bootloader" once to set the fuses.
 *
 * Function
 *   PB1 (pin 6) : feed request, same net as Pro Mini D4 (limit switch X1 / sensor X9).
 *                 HIGH = filament pulled = feed requested. External 10k pull-down (R1).
 *   PB3 (pin 2) : EXT_IN. HIGH -> T1 -> relay K1 closes -> motor supply VM on.
 *                 External 10k pull-down (R3) keeps the relay OFF whenever this pin is not driven.
 *   PB4 (pin 3) : external sensor input (board rev.B only, EXT_SENSE_ENABLED = 1).
 *                 X5 pin 2 with 10k pull-down. HIGH = sensor OK, LOW or open wire = fault.
 *                 Jumper JP (X5 signal to +5V) = external sensor not used.
 *   PB5 (pin 1) : RESET, shared with the Pro Mini reset (X3). X3 also clears a latched fault.
 *
 *   The motor supply is cut and the state is latched until reset / power cycle when
 *     - the feed request stays HIGH continuously for JAM_TIMEOUT_MS (jam), or
 *     - (rev.B) the external sensor reports a fault for EXT_FAULT_FILTER_MS, or is not OK
 *       within EXT_STARTUP_GRACE_MS after power-up.
 *
 * Changes from motor_emergency_stop_tiny85.ino (2023)
 *   - The timer is reset deterministically when the request goes LOW (the old code reset it
 *     only if the input fell during a 10 ms window, so about 1/3 of releases were missed).
 *   - Timeout measured in real time with millis() instead of counting loop passes.
 *     48 s = the effective timeout of the old code at 8 MHz (3000 passes of 10 ms delay
 *     plus Serial output time, measured in simulation: 47.9 s).
 *   - Serial removed: on ATTinyCore its RX shares PB1 and its TX (PB0) is not connected.
 *   - Short LOW glitches (contact chatter) do not reset the timer.
 *   - Fault output is high impedance, so on rev.A boards a fitted jumper on EXT_IN or a signal
 *     on X5 cannot short the pin.
 *   - Watchdog: a hang resets the MCU; a watchdog reset is treated as a fault (fail safe).
 *   - External sensor input for board rev.B.
 */
#include <avr/io.h>
#include <avr/wdt.h>

// ---- Pins (ATTinyCore numbering = PBn) ----
constexpr uint8_t PIN_REQUEST   = 1;   // PB1
constexpr uint8_t PIN_RELAY     = 3;   // PB3
constexpr uint8_t PIN_EXT_SENSE = 4;   // PB4 (rev.B)

// ---- Parameters ----
constexpr uint32_t JAM_TIMEOUT_MS    = 48000UL;  // continuous feed request that is treated as a jam
constexpr uint32_t RELEASE_FILTER_MS = 20UL;     // request must be LOW this long to end an episode

// External sensor (board rev.B). 0 on rev.A boards: PB4 is not connected there.
#ifndef EXT_SENSE_ENABLED                 // can be overridden with -DEXT_SENSE_ENABLED=1
#define EXT_SENSE_ENABLED 0
#endif
constexpr uint32_t EXT_FAULT_FILTER_MS  = 50UL;    // LOW this long while running = sensor fault
constexpr uint32_t EXT_STARTUP_GRACE_MS = 1000UL;  // sensor must report OK within this time

static bool     relayIsOn = false;
static bool     episodeActive = false;
static uint32_t episodeStartMs = 0;
static uint32_t lastHighMs = 0;
#if EXT_SENSE_ENABLED
static bool     extLowTiming = false;
static uint32_t extLowSinceMs = 0;
#endif

static void relayOn() {
  digitalWrite(PIN_RELAY, HIGH);
  pinMode(PIN_RELAY, OUTPUT);
  relayIsOn = true;
}

// Cut the motor supply and stay here until reset / power cycle.
static void latchFault() __attribute__((noreturn));
static void latchFault() {
  digitalWrite(PIN_RELAY, LOW);    // relay off at once
  pinMode(PIN_RELAY, INPUT);       // then high impedance (PORT bit is 0, so no pull-up); R3 holds it LOW
  for (;;) {
    wdt_reset();
  }
}

void setup() {
  const uint8_t resetCause = MCUSR;
  MCUSR = 0;
  wdt_disable();

  pinMode(PIN_REQUEST, INPUT);     // external pull-down R1, no internal pull-up
#if EXT_SENSE_ENABLED
  pinMode(PIN_EXT_SENSE, INPUT);   // external pull-down on rev.B, no internal pull-up
#endif

  wdt_enable(WDTO_1S);
  if (resetCause & _BV(WDRF)) {
    latchFault();                  // previous run hung: do not restart the motor by itself
  }
#if !EXT_SENSE_ENABLED
  relayOn();
#endif
}

void loop() {
  wdt_reset();
  const uint32_t now = millis();

#if EXT_SENSE_ENABLED
  if (digitalRead(PIN_EXT_SENSE) == HIGH) {
    extLowTiming = false;
    if (!relayIsOn) relayOn();     // motor supply only after the sensor has reported OK
  } else {
    if (!extLowTiming) {
      extLowTiming = true;
      extLowSinceMs = now;
    }
    if (relayIsOn && (now - extLowSinceMs) >= EXT_FAULT_FILTER_MS) latchFault();
    if (!relayIsOn && now >= EXT_STARTUP_GRACE_MS) latchFault();
  }
#endif

  if (digitalRead(PIN_REQUEST) == HIGH) {
    lastHighMs = now;
    if (!episodeActive) {
      episodeActive = true;
      episodeStartMs = now;
    } else if (now - episodeStartMs >= JAM_TIMEOUT_MS) {
      latchFault();
    }
  } else if (episodeActive && (now - lastHighMs >= RELEASE_FILTER_MS)) {
    episodeActive = false;         // request released: timer is reset
  }
}

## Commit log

2023-04-11 Create BOM
2023-04-11 Update BOM
2026-09-23 Rewrite firmware: feeder_main and jam_monitor_tiny85
    feeder_main (Arduino Pro Mini, was arduino/TMC2130_spool.ino):
    - TMC2130Stepper (deprecated) replaced by TMCStepper 0.7.3; register values unchanged
    - feed values kept; the real motion of the old firmware is reproduced with
    explicit values (2400 steps/s, 4000 steps/s^2 up, 2000 steps/s^2 down,
    4000 steps after release) without the speed jump when the request ends
    - driver configuration verified by read-back, automatic reconfiguration
    after a driver reset, latched stop on overtemperature/short circuit
    - input filter, backup jam timeout (53 s), serial messages,
    status LED on D8 (board rev.B)
    jam_monitor_tiny85 (ATtiny85, was arduino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
    [config.h, feeder_main.ino, jam_monitor_tiny85.ino]
2026-09-23 Reorganize hardware: EAGLE design, CSV BOMs, rev.B plan
    - hardware/pcb/eagle: EAGLE 9.6.2 schematic and board (the data used for
    fabrication)
    - DesignSpark files removed: the GND pour lost its connection to the GND
    net in the conversion from EAGLE (still available in tag v1.0-2023)
    - BOMs as CSV, corrected: relay G6K-2P-Y DC5, PS1 RXEF135, T1 DTC144EKA,
    timing pulley GT2 20T added
    - STEP files moved to hardware/mechanical/step
    - rev.B change plan: external input to ATtiny85 PB4, T1 -> DTC123JKA,
    R2 -> 2.2k, D3 driven from Pro Mini D8 with R4 -> 470
    Claude-Session: https://claude.ai/code/session_01CN5z7kNkBV6zKj8DLApdnx
    [BOM_dual_show.xlsx, Base_lever_L.stp, Base_lever_R.stp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]
2026-09-23 Add AVR simulation used to verify the firmware
    simavr harnesses for the ATmega328P (with a TMC2130 SPI model) and the
    ATtiny85, analysis scripts and the test scenarios. Results of the
    comparison between the 2023 and the new firmware are in tools/sim/README.md.
    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
2026-09-23 Bilingual README, principle and wiring docs, images, changelog
    - README in Japanese and English
    - docs/principle.md: problem, construction, feed control, drive geometry,
    feed values (old settings, old real motion, new firmware), protection
    - docs/wiring.md: connectors, jumpers, pin assignment, power path
    - images stored in docs/images instead of external links
    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
2026-09-23 Remove assembly STEP with manufacturer models; add outline drawing and assembly parts list
    assy_top_dual.stp contained 3D models of purchased parts provided by their manufacturers. It is replaced by docs/images/assembly_outline.png (front, top, right side and isometric views generated from the model) and hardware/mechanical/assembly_parts.csv. Motor mount added to the mechanical BOM.
    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
    [assembly_parts.csv, bom.csv]
2026-09-23 Mechanical BOM: quantities from the assembly model
    NFS5-2020-230 x2 and M3 10 mm spacers x8 added; NFS5-2020-250 10, NETW8 4, corner brackets 28; acrylic plate with hole listed separately; self-made parts linked to their STEP files.
    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
    [bom.csv]
2026-09-23 Add STEP files of the six self-made acrylic plates
    Extracted unchanged from the assembly model (volumes and outlines verified). README, BOM and CHANGELOG updated.
    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
    [20x300x3.stp, 270x290_plate_wall.stp, 270x300_plate_wall.stp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]
2026-09-23 Control board rev.B: EAGLE files, schematic PDF, BOM and docs
    The board was revised in Autodesk Fusion and exported in EAGLE 9.7.0
    format. rev.A (as built) is kept in tag pcb-rev.A.
    - EXT_SENSE: X5 pin 2 and JP2 pin 1 to ATtiny85 PB4 through R6 10k,
    pull-down R5 10k
    - T1 DTC123JKA, R2 2.2k, D3 driven from Pro Mini D8 with R4 470
    - Chip resistors 0603 -> 0805
    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
    [bom.csv, spool_tmc2130_b.brd, spool_tmc2130_b.sch]

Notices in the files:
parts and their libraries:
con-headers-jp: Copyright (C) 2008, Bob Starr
